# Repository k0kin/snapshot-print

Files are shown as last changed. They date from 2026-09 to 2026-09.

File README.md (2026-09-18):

# Listo para imprimir — Snap Shot

Todo en **PETG**, 0.2 mm de capa, 100 % de relleno en las piezas del mecanismo (705, 706,
707) y 40 % o más en el resto. Cada archivo aquí está revisado y no va a cambiar. Faltan
solo los clips de sujeción al gancho, la caja de la electrónica y el soporte de pantalla.

## Primero, para elegir los ajustes

| Archivo | Cant. | Nota |
|---|---|---|
| `105_socket_gauge.stl` | 1 | Cupón: prueba los zócalos y elige el diámetro antes de imprimir los rieles |
| `104_dowel_pin_card.stl` | 1 | Tarjeta con 6 pasadores en 3 diámetros: elige el que entre a presión en la mitad A y deslice en la B, antes de unir la barra |

## Barra principal (la columna vertebral, lleva las cámaras)

| Archivo | Cant. | Impresión | Nota |
|---|---|---|---|
| `101_bar_half_A.stl` | 1 | Cara inferior sobre la cama, canal hacia arriba | Mitad trasera, X 0–178.4 |
| `102_bar_half_B.stl` | 1 | Igual | Mitad delantera, X 178.4–356 |
| `103_channel_lid_A.stl` | 1 | Plana | Tapa del canal, mitad A |
| `103_channel_lid_B.stl` | 1 | Plana | Tapa del canal, mitad B |
| `601_camera_clamp.stl` | 2 | Marco hacia abajo | Sujetador de la cámara, uno por cámara |

**La cámara tiene una sola orientación correcta.** El escalón donde apoya lleva un pin que
entra en uno de los agujeros del módulo: bien puesta, la placa asienta a fondo; girada,
queda 1.5 mm levantada y los tornillos no entran. Si no asienta, gírala, no la fuerces.

**Unión de las mitades:** el pasador se mete **a fondo en la mitad A** (entra 15.5 mm) y
la mitad B se desliza sobre los 4.5 mm que sobresalen. Está hecho así a propósito: el
tornillo del poste central pasa a 1.2 mm del asiento en B.

## Postes

| Archivo | Cant. | Impresión | Nota |
|---|---|---|---|
| `401_post_outer.stl` | 4 | De pie, con el pie sobre la cama | Postes exteriores, ambos lados |
| `402_post_mid.stl` | 2 | De pie, con el pie sobre la cama | Poste central; los dos cubos horizontales del eje pueden necesitar un soporte corto |

## Rieles

| Archivo | Cant. | Nota |
|---|---|---|
| `501_rail_A_seg1_chamfer_L.stl` | 1 | Riel A trasero, lado +Y |
| `501_rail_A_seg1_chamfer_R.stl` | 1 | Riel A trasero, lado −Y |
| `501_rail_A_seg2_chamfer_L.stl` | 1 | Riel A delantero, lado +Y |
| `501_rail_A_seg2_chamfer_R.stl` | 1 | Riel A delantero, lado −Y |
| `502_rail_B1_rear.stl` | 2 | Riel B trasero, uno por lado |
| `503_rail_B2_front.stl` | 2 | Riel B delantero, uno por lado |

De costado, con la cara exterior sobre la cama.

## Barras de ArUco

| Archivo | Cant. | Marcadores que lleva |
|---|---|---|
| `701_fiducial_bar_rear_L.stl` | 1 | IDs 1 y 3 |
| `701_fiducial_bar_rear_R.stl` | 1 | IDs 0 y 2 |
| `702_fiducial_bar_front_L.stl` | 1 | IDs 5 y 7 |
| `702_fiducial_bar_front_R.stl` | 1 | IDs 4 y 6 |

Cara exterior sobre la cama; la cara superior con los rebajes no se toca. Los marcadores de
papel: `aruco_markers_print_at_100pct.svg`, **al 100 %, sin ajustar a página**, en papel
mate. Son de 5 mm; se pegan en los rebajes de 7.1 mm.

## Mecanismo de la palanca

| Archivo | Cant. | Impresión | Nota |
|---|---|---|---|
| `705_splice_A_L.stl` / `705_splice_A_R.stl` | 1 c/u | Columna vertical, cabeza arriba | Carro del riel A |
| `705_splice_B_L.stl` / `705_splice_B_R.stl` | 1 c/u | Igual | Carro del riel B |
| `706_crank.stl` | 4 | Plana | |
| `504_lift_lever_A.stl` | 1 | Plana | Una marca |
| `504_lift_lever_B.stl` | 1 | Plana | Dos marcas |
| `707_detent_ring.stl` | 2 | **Cara del saliente hacia abajo, pivotes arriba** | Al sacarlo, flexiona el brazo con el dedo: debe ceder con presión suave. Si no cede, avisar antes de montar |

## Total: 27 archivos, 38 piezas impresas, más la hoja de ArUco

Un tirón normal de la palanca necesita medio newton. **Si no se mueve, no está trabada:
algo está mal. No la fuerces** (límite 15 N en el mango).

### Vigilar en la primera impresión
- El labio de 0.5 mm junto a la ranura del LED en la barra: un perímetro, sin carga; si el slicer lo omite, no importa.
- El voladizo de 2 mm bajo el escalón de la cámara, dentro de la barra.
- El sujetador de cámara: al apretar debe flexionar ligeramente; si queda plano sin resistencia, avisar.

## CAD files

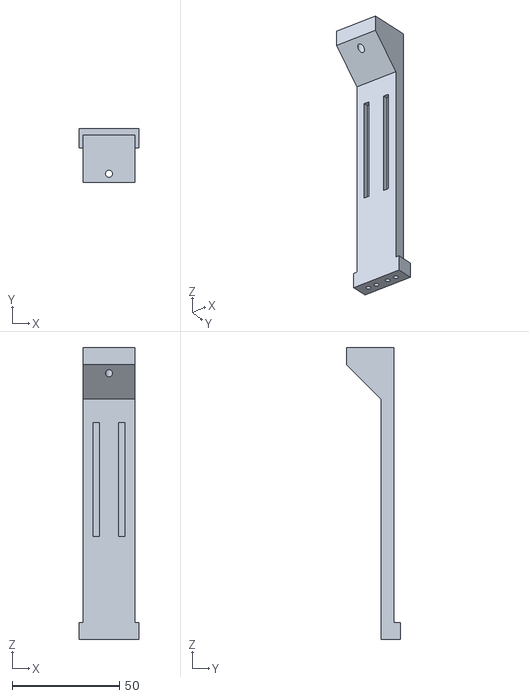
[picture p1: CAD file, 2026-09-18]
401_post_outer.stl
28.0 x 25.0 x 136.0

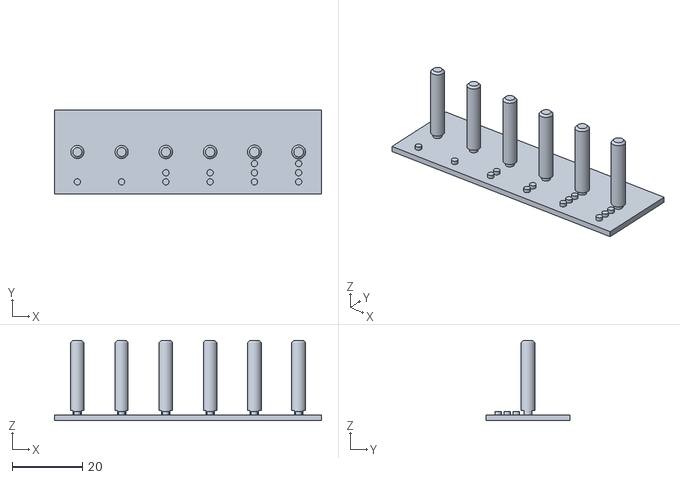
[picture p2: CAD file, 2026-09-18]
104_dowel_pin_card.stl
76.0 x 24.0 x 22.8

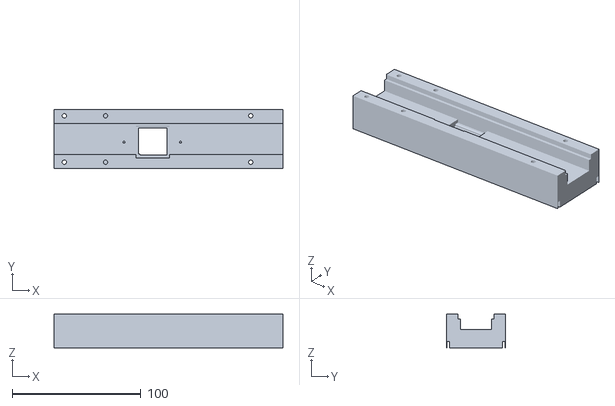
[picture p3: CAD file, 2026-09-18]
102_bar_half_B.stl
177.6 x 46.0 x 26.0

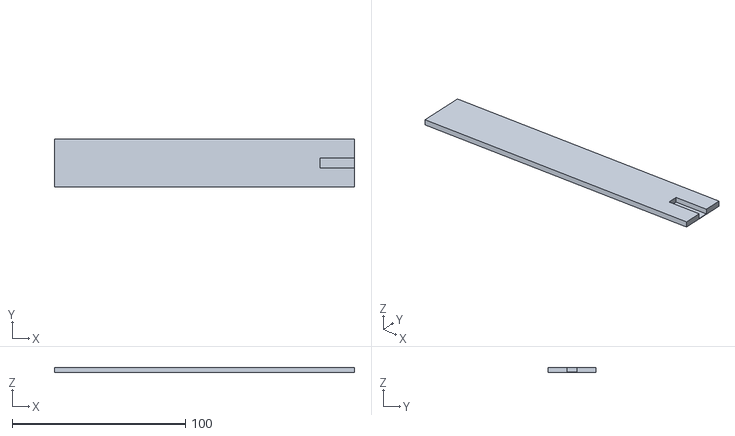
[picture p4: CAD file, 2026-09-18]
103_channel_lid_B.stl
173.0 x 27.5 x 3.10

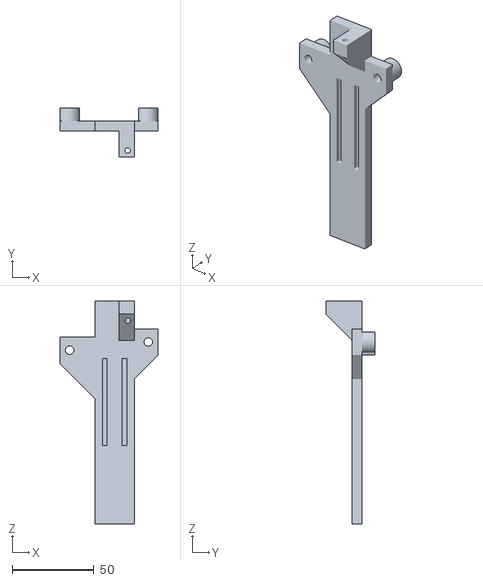
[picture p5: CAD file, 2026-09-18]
402_post_mid.stl
60.0 x 30.0 x 136.0

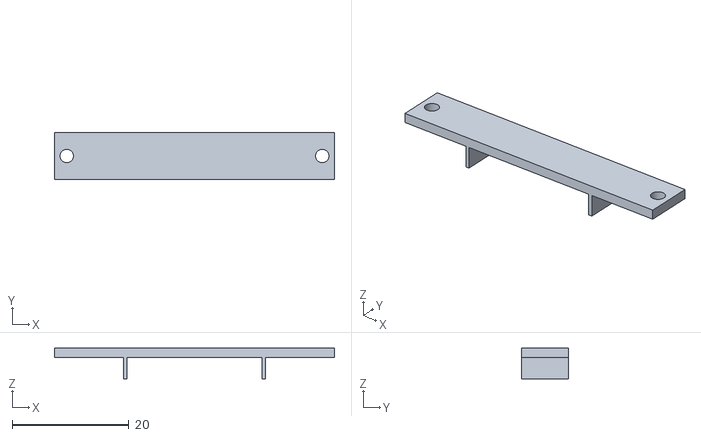
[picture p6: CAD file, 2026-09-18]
601_camera_clamp.stl
48.0 x 8.00 x 5.24

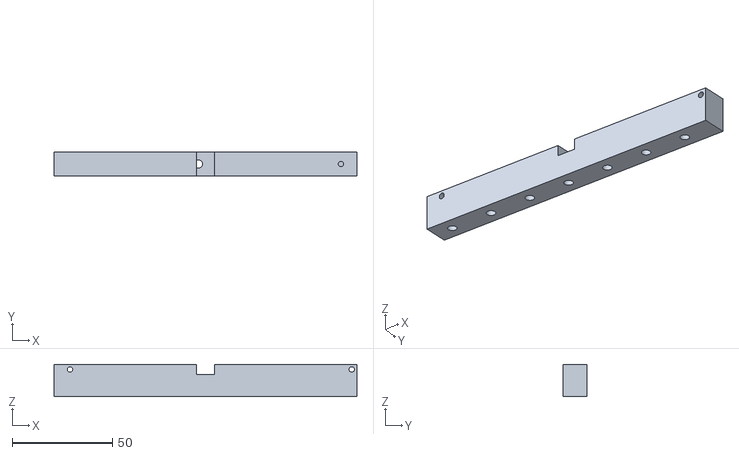
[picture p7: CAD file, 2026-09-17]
502_rail_B1_rear.stl
151.0 x 12.0 x 16.0

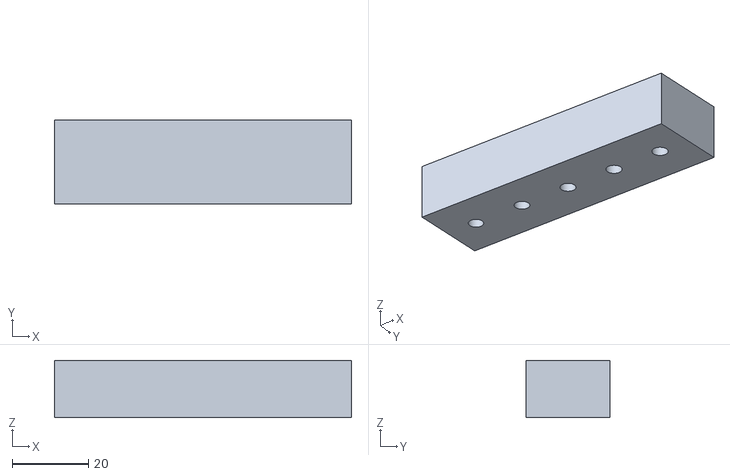
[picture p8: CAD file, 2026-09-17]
105_socket_gauge.stl
78.0 x 22.0 x 15.0

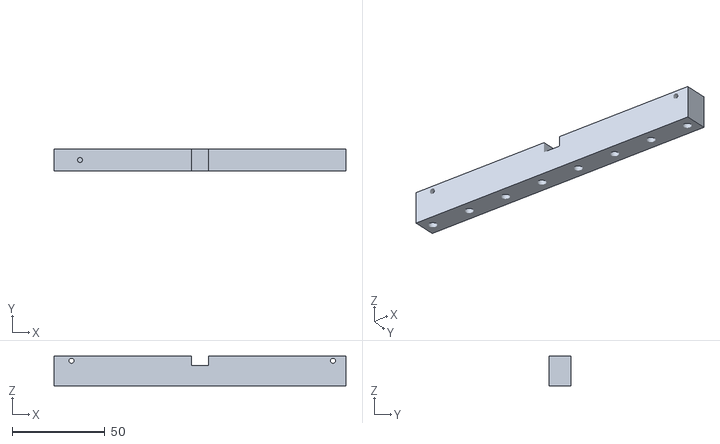
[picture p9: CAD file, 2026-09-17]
503_rail_B2_front.stl
157.0 x 12.0 x 16.0

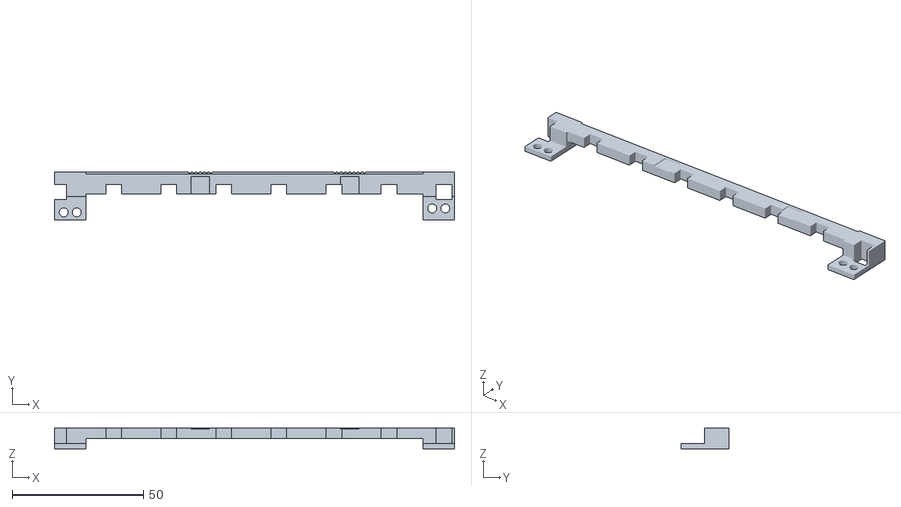
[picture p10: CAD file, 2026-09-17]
702_fiducial_bar_front_L.stl
152.6 x 18.5 x 8.00

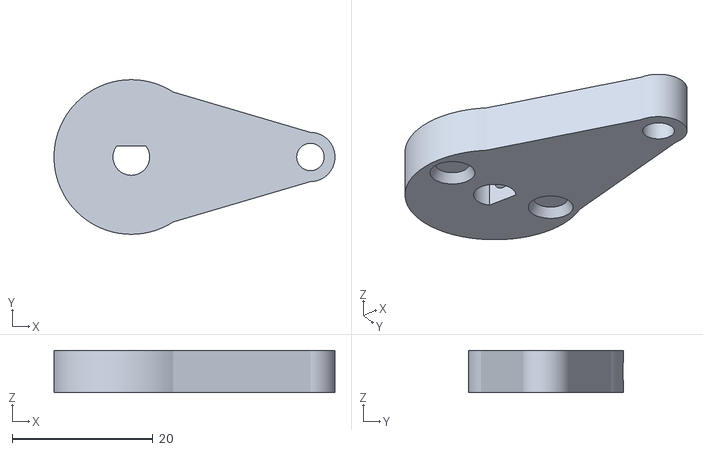
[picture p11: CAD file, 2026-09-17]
706_crank.stl
40.0 x 22.0 x 6.00

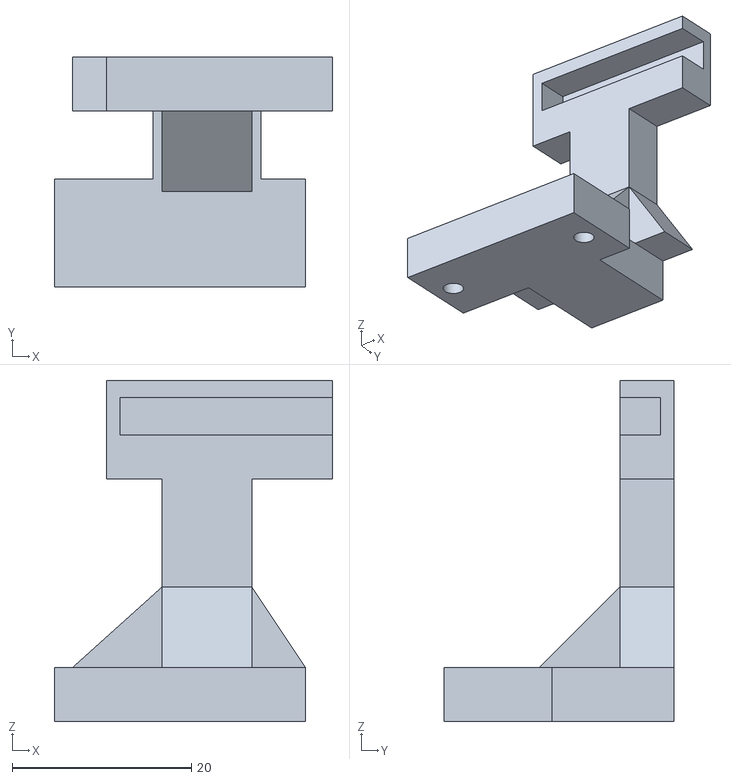
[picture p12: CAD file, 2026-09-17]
705_splice_B_L.stl
31.0 x 25.6 x 38.0

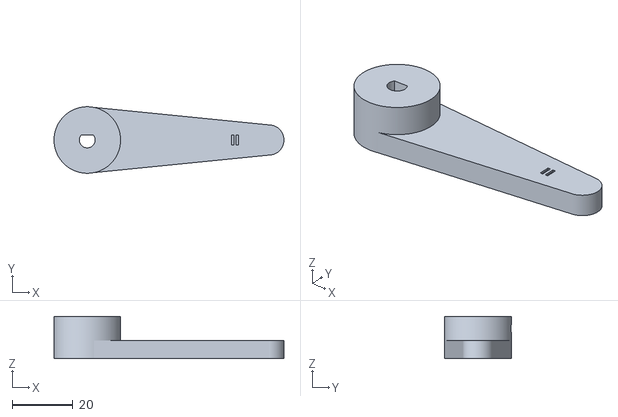
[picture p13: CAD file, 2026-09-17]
504_lift_lever_B.stl
76.0 x 22.0 x 14.0

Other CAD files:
101_bar_half_A.stl
103_channel_lid_A.stl
701_fiducial_bar_rear_R.stl
501_rail_A_seg2_chamfer_L.stl
501_rail_A_seg1_chamfer_R.stl
501_rail_A_seg1_chamfer_L.stl
501_rail_A_seg2_chamfer_R.stl
504_lift_lever_A.stl
701_fiducial_bar_rear_L.stl
702_fiducial_bar_front_R.stl
705_splice_A_L.stl
705_splice_A_R.stl
705_splice_B_R.stl
707_detent_ring.stl

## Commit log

2026-09-17 Snap Shot: piezas listas para imprimir (20 STL + hoja ArUco)
    [105_socket_gauge.stl, 501_rail_A_seg1_chamfer_L.stl, 501_rail_A_seg1_chamfer_R.stl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]
2026-09-18 Barra principal, tapas, tarjeta de pasadores, sujetador de cámara y postes (28 piezas)
    [101_bar_half_A.stl, 102_bar_half_B.stl, 103_channel_lid_A.stl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]
